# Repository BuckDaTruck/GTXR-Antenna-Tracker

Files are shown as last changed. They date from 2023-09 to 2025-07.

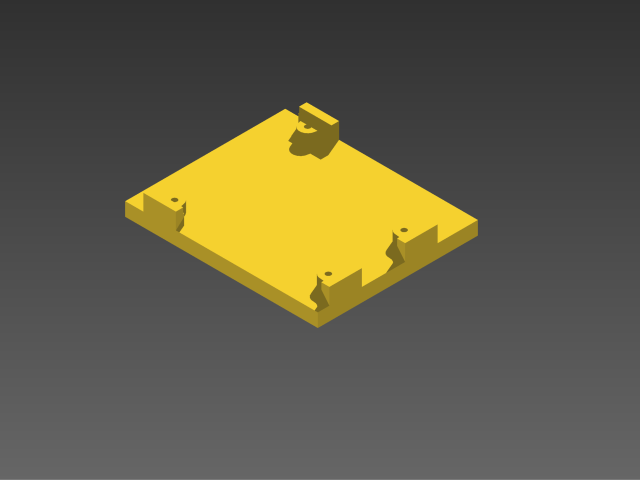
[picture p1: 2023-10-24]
cad/arduino-mounting-bracket-1.snapshot.4/Renderings/Image.png

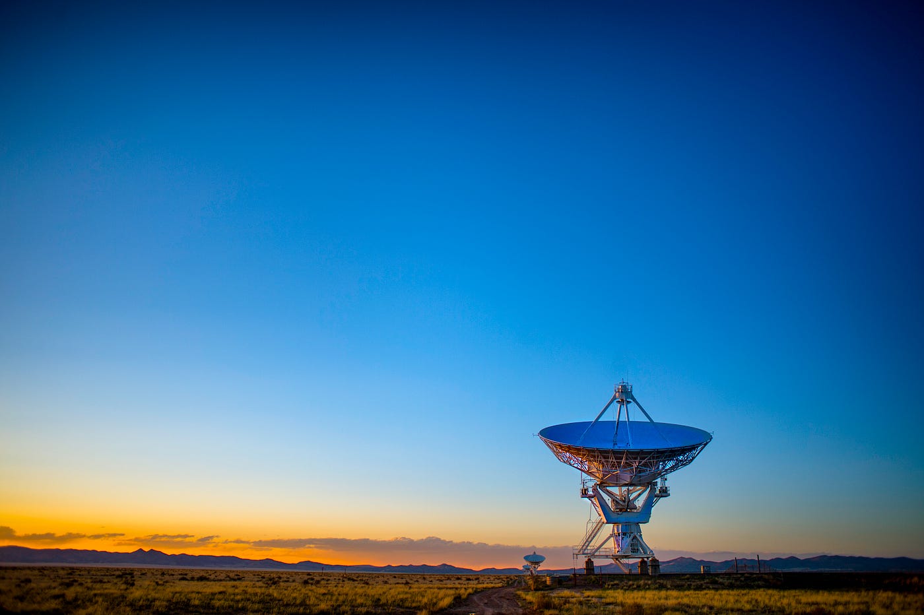
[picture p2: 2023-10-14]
resources/Calculating /0_9QViUdhbDSrmNYS7.jpg

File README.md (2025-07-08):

# GTXR Antenna Tracker

Antenna tracker and ground station software built for the Georgia Tech Experimental Rocketry (GTXR) team. The project combines Python utilities, Arduino firmware, and CAD models for a two-axis tracking platform.

## Overview

The system reads GPS telemetry from a vehicle or Featherweight tracker and calculates the azimuth and elevation required to aim a directional antenna. A stepper-motor driven gimbal points the antenna while a Python application provides a simple user interface and communication with the Arduino controller.

This repository contains everything needed to build the tracker:

- **Python application** (`App/`) for reading GPS data and sending commands to the gimbal
- **Firmware** (`Tracker-Hardware/Firmware/`) for an Arduino-based controller
- **CAD files** (`cad/`) for printing or machining mechanical parts
- **Reference materials and test tools** (`resources/`, `test tools/`)
- **Hardware list** (`PARTS_LIST.md`)

## Repository Layout

```
App/                  Python scripts and GUI assets
Tracker-Hardware/     Arduino firmware
cad/                  STL, STEP, and DXF models for the tracker frame
Assets/               Logos and icons used by the app
FilteredData/         Example telemetry log
resources/            Reference projects and documentation
```

## Software Setup

1. Install Python 3.x
2. Install dependencies:
   ```bash
   pip install numpy pynmea2 pyserial wxPython
   ```
   (Depending on your system you may need additional packages.)
3. Connect the GPS receiver and Arduino-based tracker to your computer.

## Running the Tracker

The main Python application is `App/v2.py`. Launch it with:

```bash
python3 App/v2.py
```

The program listens to GPS data on a serial port and outputs azimuth and elevation commands to the microcontroller. Configure the serial port names in the script if they differ from your setup.

## Hardware and Firmware

The hardware design uses an Arduino with a CNC shield to drive two stepper motors. CAD models for the frame and gears live under `cad/`. Electronic components are listed in `PARTS_LIST.md`.

To load the firmware:

1. Open `Tracker-Hardware/Firmware/Firmware.ino` in the Arduino IDE.
2. Select your board and port.
3. Compile and upload.

## Data and Resources

Example telemetry logs are provided in `FilteredData` and `data.csv`. Additional research code and documentation can be found in the `resources` directory.

## Contact

Developed by Buckley Wiley for GTXR in the fall of 2023. For questions email [buckley@buckleywiley.com](mailto:buckley@buckleywiley.com).

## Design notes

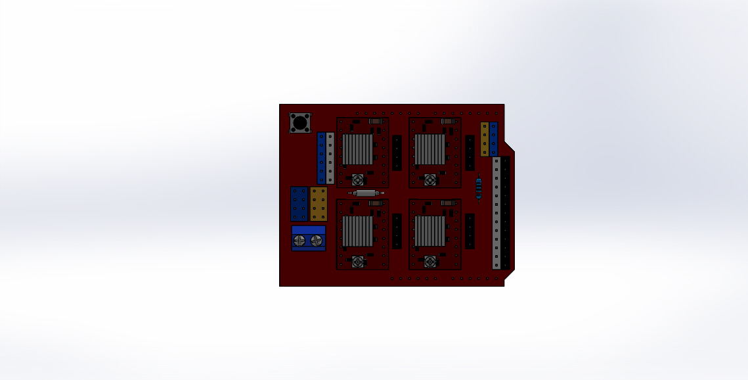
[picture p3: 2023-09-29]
cad/arduino-uno-cnc-shield-v3-a4988-suruculu-1.snapshot.1/Arduino Uno CNC Shield V3 Resim1.JPG

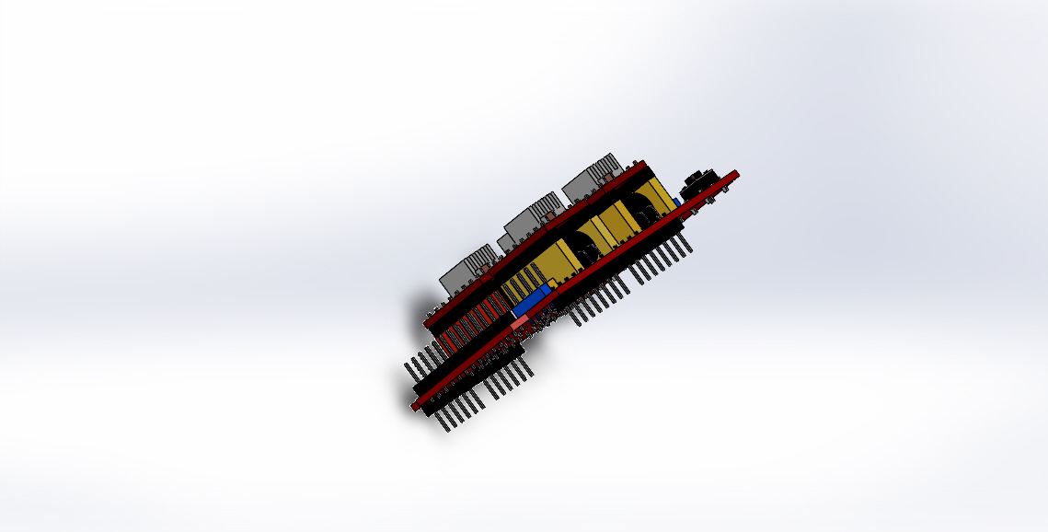
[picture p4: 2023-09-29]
cad/arduino-uno-cnc-shield-v3-a4988-suruculu-1.snapshot.1/Arduino Uno CNC Shield V3 Resim2.JPG

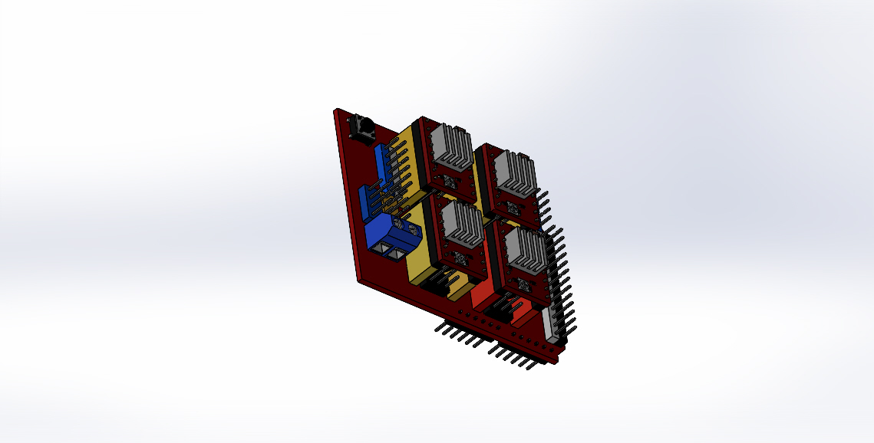
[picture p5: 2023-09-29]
cad/arduino-uno-cnc-shield-v3-a4988-suruculu-1.snapshot.1/Arduino Uno CNC Shield V3 Resim3.JPG

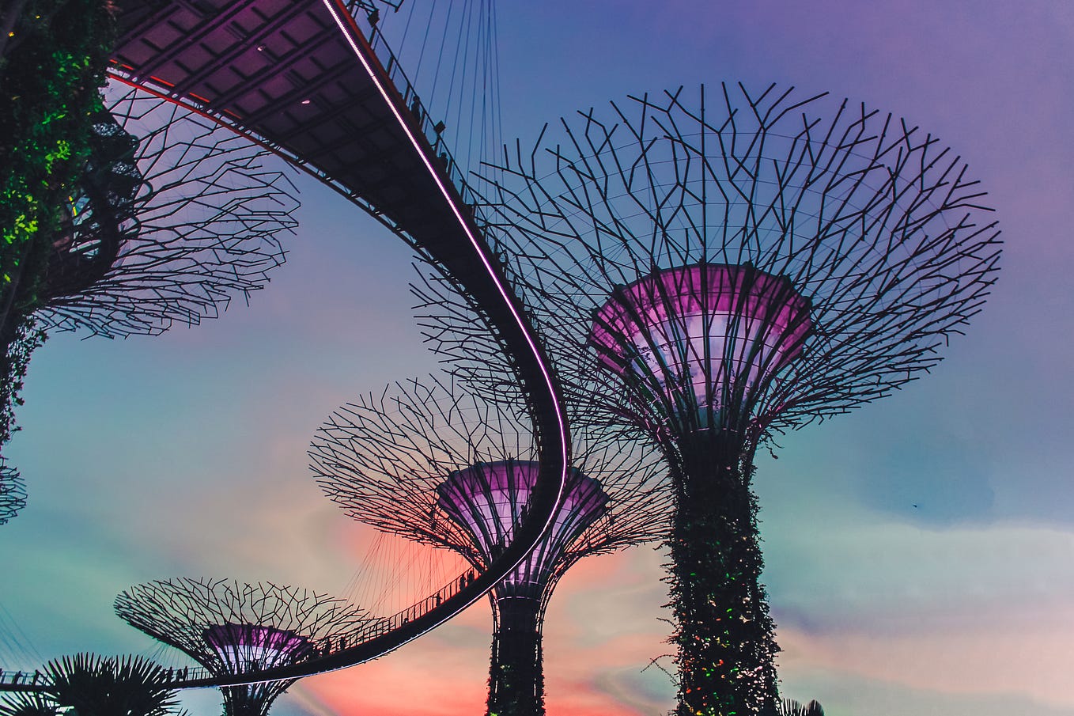
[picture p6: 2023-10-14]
resources/Calculating /0_bAgEUAvxvYWlByFD.jpg

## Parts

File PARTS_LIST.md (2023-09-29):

Parts:
Deep Groove Ball Bearing 80x100x10mm:
    https://a.co/d/d4j6g4g
Deep Groove Ball Bearings 50mm Inner Dia 65mm OD 7mm Bore:
    https://a.co/d/4pUVKYt
24V Power Supply
    https://a.co/d/egXIh8z  
Professional CNC Kit for arduino, GRBL CNC Shield +Kuman Board + RAMPS 1.4 Mechanical Switch Endstop + DRV8825 A4988 GRBL Stepper Motor Driver with Heat Sink + Nema 17 Stepper Motor
    https://a.co/d/038nOvT
GPS Reciever:
    https://a.co/d/1DIF7u9
Featherweight GPS Tracker:
    https://www.featherweightaltimeters.com/store/p22/Featherweight_GPS_Tracker_%28upd%29.html
Baltic Birch Plywood, 6 mm:
    https://a.co/d/dV6v9bX
Hardware:
    1/4" Threaded Inserts:
        https://a.co/d/egDEeNk
    8-32 x 1/2" Button Head Socket Cap Bolts:
        https://a.co/d/85Pqs9Q
    1/4-20 x 1" Button Head Socket Cap Bolts:
        https://a.co/d/cY6eXtJ

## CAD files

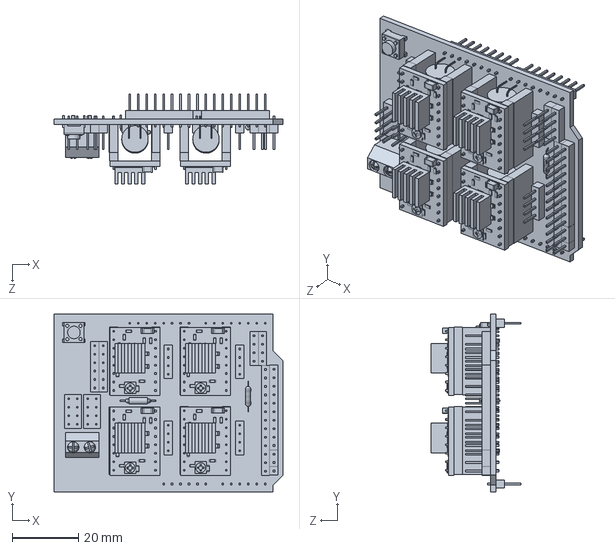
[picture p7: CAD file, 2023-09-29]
cad/arduino-uno-cnc-shield-v3-a4988-suruculu-1.snapshot.1/Arduino Uno CNC Shield V3.SLDPRT
69.0 x 53.5 x 27.1 mm

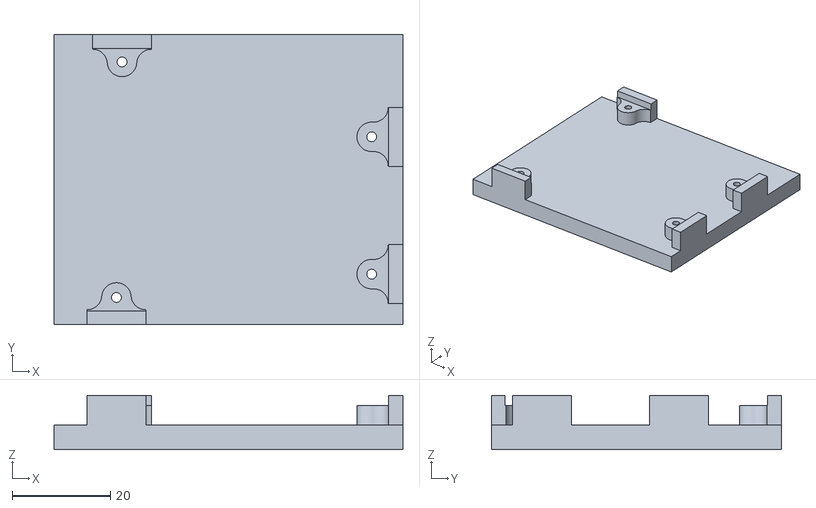
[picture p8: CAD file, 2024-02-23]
cad/Final Cad/Arduino Mount.stl
71.0 x 59.0 x 11.0

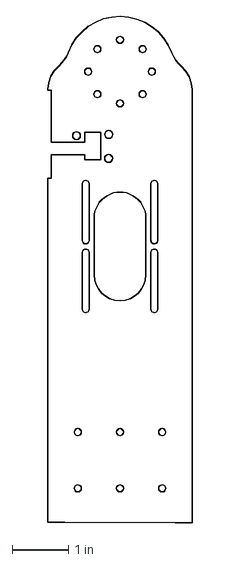
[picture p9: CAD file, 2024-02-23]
cad/hey.dxf
2.56 x 8.99 in

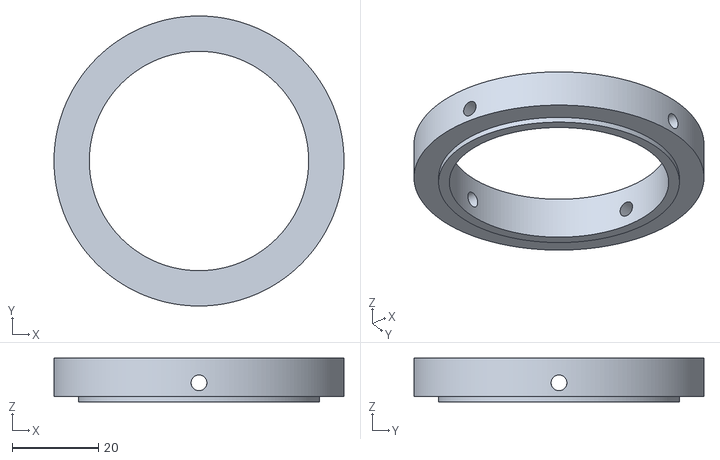
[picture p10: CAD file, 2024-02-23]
cad/Bearing holder.stl
67.2 x 67.2 x 10.2

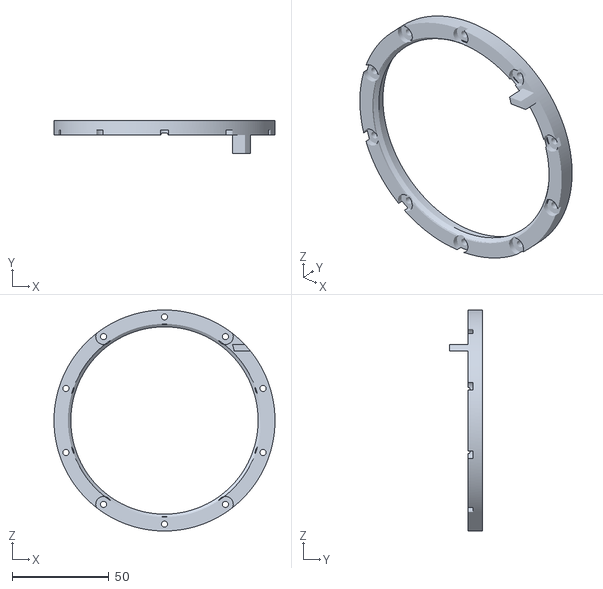
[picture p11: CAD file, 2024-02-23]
cad/Final Cad/pan bearing retainer.stl
114.3 x 17.3 x 114.3

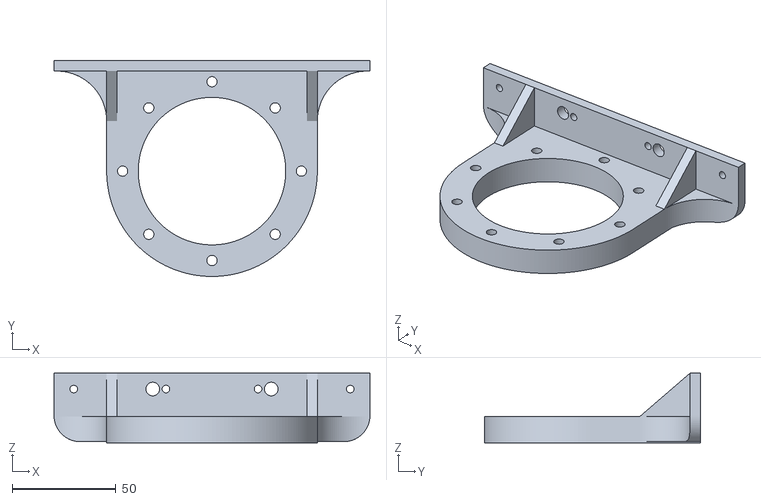
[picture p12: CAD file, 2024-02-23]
cad/Final Cad/antena tray connector.stl
152.4 x 104.1 x 33.5

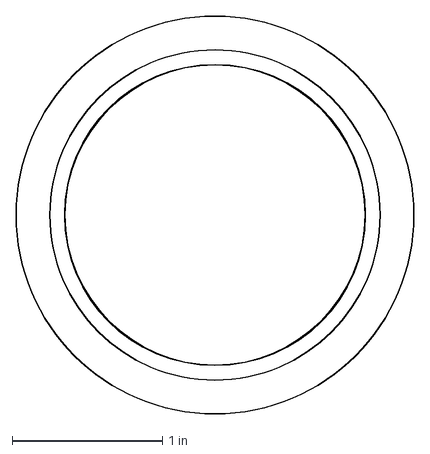
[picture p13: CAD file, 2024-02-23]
cad/Pillar.dxf
2.65 x 2.64 in

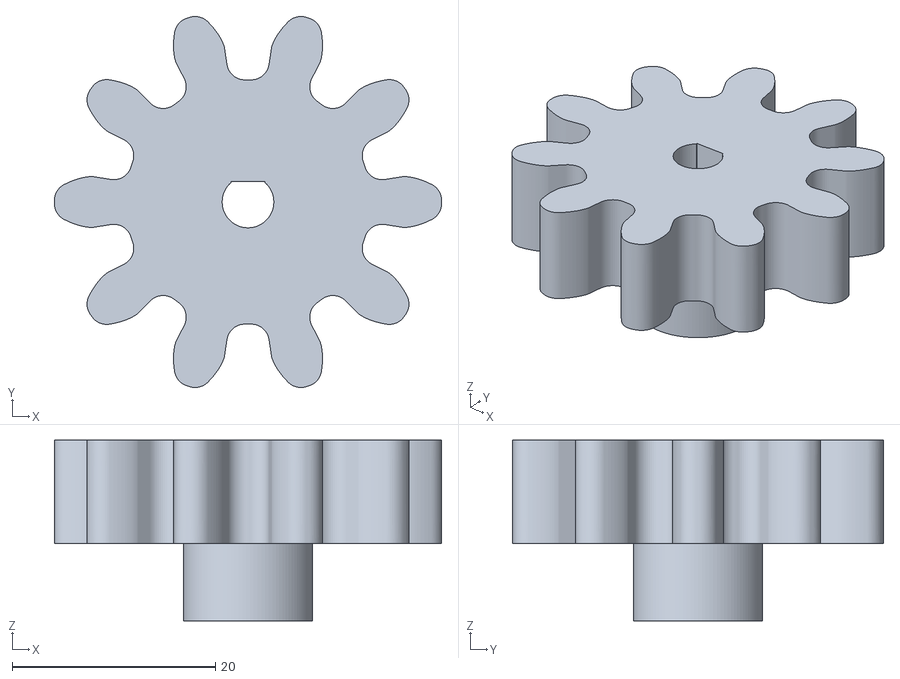
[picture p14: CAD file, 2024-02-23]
cad/Final Cad/stepper gear pan.stl
38.1 x 36.5 x 17.8

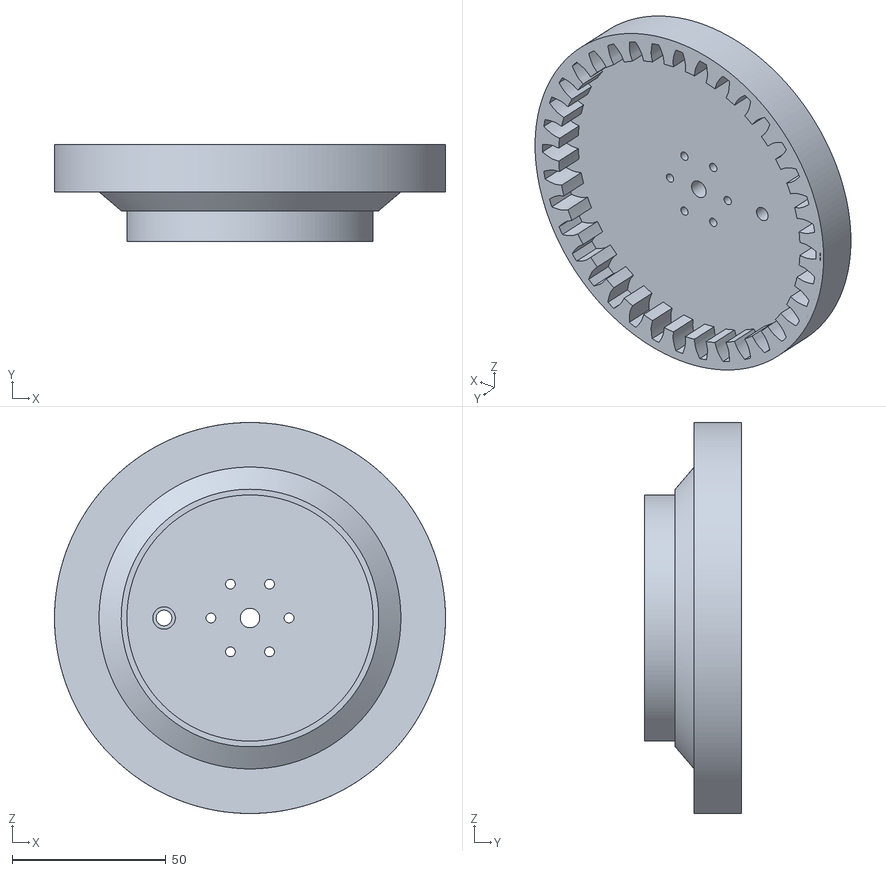
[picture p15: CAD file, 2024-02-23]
cad/Final Cad/Internal gear pan.stl
127.1 x 31.6 x 127.1

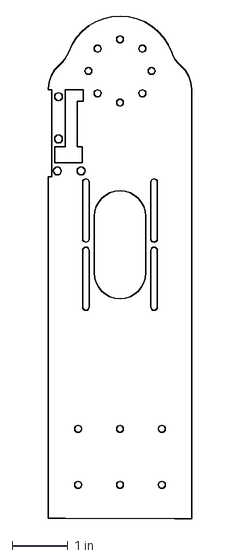
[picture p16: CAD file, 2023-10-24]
cad/Altitude pillar.dxf
2.56 x 8.99 in

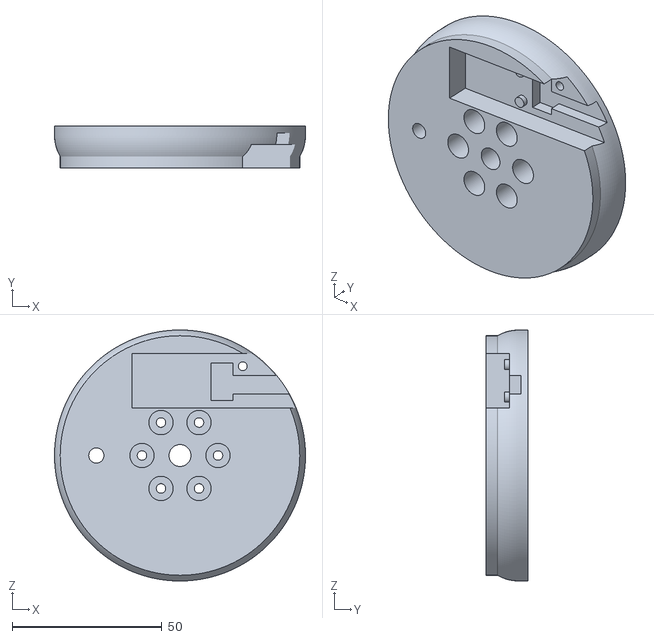
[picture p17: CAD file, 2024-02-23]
cad/Final Cad/Bottom mount.stl
83.8 x 14.0 x 83.8

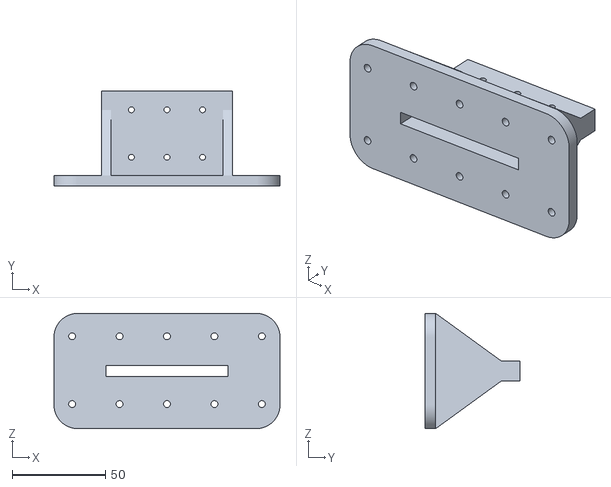
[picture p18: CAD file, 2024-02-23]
cad/Final Cad/Pylon Stand.stl
121.0 x 50.8 x 61.7

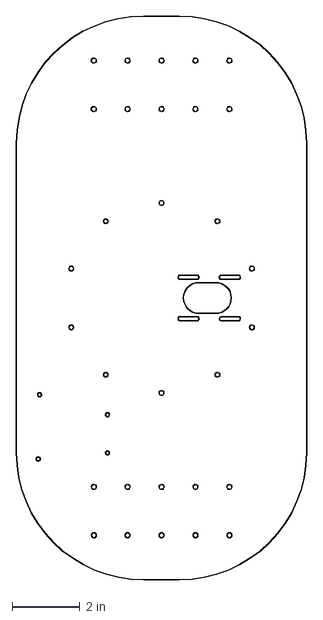
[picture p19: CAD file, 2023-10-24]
cad/Pan Plate.dxf
8.56 x 16.6 in

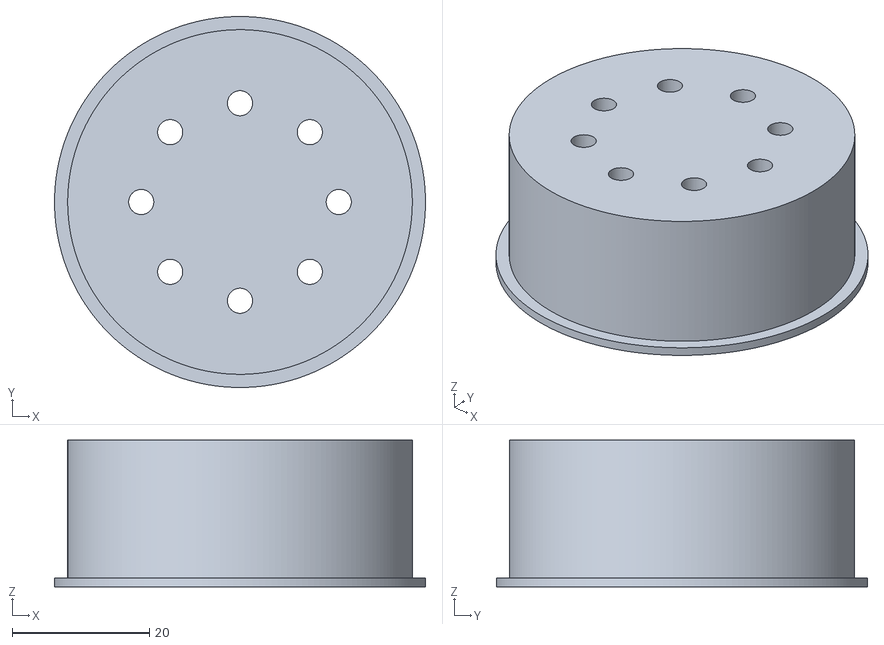
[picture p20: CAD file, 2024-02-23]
cad/Final Cad/azimuth bearing connector.stl
54.0 x 54.0 x 21.3

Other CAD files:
cad/pan spur gear.stl
cad/ardunio_mount.stl
cad/Pan tray mount.stl
cad/bottom clamp.stl
cad/Bewaring holder.stl
cad/Body1.stl
cad/Final Cad/Bearing Retainer.stl
cad/Final Cad/Pan Plate mount.stl
cad/Final Cad/Tilt gear with home.stl
cad/Final Cad/Tilt gear.stl
cad/Switch.SLDPRT
cad/antenna carrier plate.dxf
cad/arduino-mounting-bracket-1.snapshot.4/Renderings/Uno R3-mount.ipt
cad/arduino-mounting-bracket-1.snapshot.4/Uno R3-mount.ipt
cad/arduino-uno-cnc-shield-v3-a4988-suruculu-1.snapshot.1/Arduino Uno CNC Shield V3.stl
cad/azimuth bearing connector.stl
cad/azimuth gear with endstop.stl
cad/azimuth pillar.dxf
cad/internal gear pan.stl
cad/plateconnector.stl
cad/stepper gear azimuth.stl
cad/tripod mount.stl
cad/vertical connector.stl

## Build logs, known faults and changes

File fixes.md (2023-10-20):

Traceback (most recent call last):
  File "/Users/buckleywiley/Projects/GTXR internship/GTXR-Antenna-Tracker/calculator.py", line 557, in OnInputChange
    self.update_calculations()
  File "/Users/buckleywiley/Projects/GTXR internship/GTXR-Antenna-Tracker/calculator.py", line 545, in update_calculations
    self.ser.write(Altitude_bytes)
  File "/Library/Frameworks/Python.framework/Versions/3.11/lib/python3.11/site-packages/serial/serialposix.py", line 615, in write
    raise PortNotOpenError()
serial.serialutil.PortNotOpenError: Attempting to use a port that is not open
{'lat': 0.0, 'lon': 0.0, 'elv': 0.0}
{'lat': 32.0, 'lon': 32.0, 'elv': 4343.0}
Results:
Distance: 2961.871 miles
Azimuth: 40.4895°
Altitude: -22.0024°
Traceback (most recent call last):
  File "/Users/buckleywiley/Projects/GTXR internship/GTXR-Antenna-Tracker/calculator.py", line 557, in OnInputChange
    self.update_calculations()
  File "/Users/buckleywiley/Projects/GTXR internship/GTXR-Antenna-Tracker/calculator.py", line 545, in update_calculations
    self.ser.write(Altitude_bytes)
  File "/Library/Frameworks/Python.framework/Versions/3.11/lib/python3.11/site-packages/serial/serialposix.py", line 615, in write
    raise PortNotOpenError()
serial.serialutil.PortNotOpenError: Attempting to use a port that is not open
Opened Serial Port (Featherweight GPS): /dev/cu.Bluetooth-Incoming-Port
Selected Serial Port (Featherweight GPS): /dev/cu.Bluetooth-Incoming-Port
1: Serial Port: /dev/cu.Bluetooth-Incoming-Port, Description: n/a
Traceback (most recent call last):
  File "/Users/buckleywiley/Projects/GTXR internship/GTXR-Antenna-Tracker/calculator.py", line 450, in rescan_serial_ports
    self.serial_port_choice.Clear()
    ^^^^^^^^^^^^^^^^^^^^^^^
AttributeError: 'Example' object has no attribute 'serial_port_choice'
1: Serial Port: /dev/cu.Bluetooth-Incoming-Port, Description: n/a
Traceback (most recent call last):
  File "/Users/buckleywiley/Projects/GTXR internship/GTXR-Antenna-Tracker/calculator.py", line 450, in rescan_serial_ports
    self.serial_port_choice.Clear()
    ^^^^^^^^^^^^^^^^^^^^^^^
AttributeError: 'Example' object has no attribute 'serial_port_choice'
1: Serial Port: /dev/cu.Bluetooth-Incoming-Port, Description: n/a
Traceback (most recent call last):
  File "/Users/buckleywiley/Projects/GTXR internship/GTXR-Antenna-Tracker/calculator.py", line 450, in rescan_serial_ports
    self.serial_port_choice.Clear()
    ^^^^^^^^^^^^^^^^^^^^^^^
AttributeError: 'Example' object has no attribute 'serial_port_choice'
1: Serial Port: /dev/cu.Bluetooth-Incoming-Port, Description: n/a
Traceback (most recent call last):
  File "/Users/buckleywiley/Projects/GTXR internship/GTXR-Antenna-Tracker/calculator.py", line 450, in rescan_serial_ports
    self.serial_port_choice.Clear()
    ^^^^^^^^^^^^^^^^^^^^^^^
AttributeError: 'Example' object has no attribute 'serial_port_choice'

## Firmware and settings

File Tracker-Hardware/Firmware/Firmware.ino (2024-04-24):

#include <CNCShield.h>

#define NO_OF_STEPS 6000
#define SLEEP_BETWEEN_STEPS_MS 3
#define SPEED_STEPS_PER_SECOND 475
const int buttonTilt = 9;  // Pin for tilt limit switch
const int buttonPan = 10;  // Pin for pan limit switch
bool stopTilt = false;
bool stopPan = false;
int tiltState = 1;
int PanState = 1;
CNCShield cnc_shield;
StepperMotor *motorTilt = cnc_shield.get_motor(0);
StepperMotor *motorPan = cnc_shield.get_motor(1);

int currentPanPosition = 0;
int currentTiltPosition = 0;

void setup() {
  Serial.begin(115200);
  Serial.println("I am Alive");
  pinMode(buttonPan, INPUT_PULLUP);
  pinMode(buttonTilt, INPUT_PULLUP);

  cnc_shield.begin();
  cnc_shield.enable();
  home();
}

void home() {
   motorPan->set_dir(COUNTER);
  motorTilt->set_dir(COUNTER);
  motorPan->set_speed(SPEED_STEPS_PER_SECOND);
  motorTilt->set_speed(SPEED_STEPS_PER_SECOND);
  motorPan->step(125);
  motorTilt->step(125);

  motorPan->set_dir(CLOCKWISE);
  motorTilt->set_dir(CLOCKWISE);

  while (stopPan == false) {
    int panState = digitalRead(buttonPan);
    motorPan->step();
    delay(SLEEP_BETWEEN_STEPS_MS);
    if (panState == LOW) {
      stopPan = true;
    }
  }

  while (stopTilt == false) {
    int tiltState = digitalRead(buttonTilt);
    motorTilt->step();
    delay(SLEEP_BETWEEN_STEPS_MS);
    if (tiltState == LOW) {
      stopTilt = true;
    }
  }
  stopTilt = false;
  stopPan = false;
  tiltState = 1;
  PanState = 1;
  // Reset positions
  currentPanPosition = 0;
  currentTiltPosition = 0;
  moveMotorsToAngle(10, 15);
}
void loop() {
  if (Serial.available()) {  //example command for this sentax "M3 175" 3 degree pan 175 tilt
    String command = Serial.readStringUntil('\n');
    if (command.startsWith("M")) {
      Serial.println("Moving!");
      int separatorIndex = command.indexOf(' ');
      int panAngle = command.substring(1, separatorIndex).toInt();
      int tiltAngle = command.substring(separatorIndex + 1).toInt();
      //Serial.println("Angles Pan" + panAngle.toString() + "Tilt" + tiltAngle.toString());
      moveMotorsToAngle(panAngle, tiltAngle);
    } else if (command.startsWith("H")) {
      Serial.println("homing!");
      home();
    }
  }
  /*if (Serial.available() > 0) {// this is for the python script
  
    char command = Serial.read();
    if (command == 'H') {
      home();
    } else if (command == 'M') {

      if (Serial.available() >= 8) {
        int panAngle, tiltAngle;
        Serial.readBytes((char *)&panAngle, sizeof(panAngle));
        Serial.readBytes((char *)&tiltAngle, sizeof(tiltAngle));
        moveMotorsToAngle(panAngle, tiltAngle);
      }
      
  }*/
}
void moveMotorsToAngle(int panAngle, int tiltAngle) {
  // Calculate steps from angles
  if (panAngle > 340) {
    panAngle = 340;
  }
  if (tiltAngle > 90) {
    tiltAngle = 90;
  }
  
  int targetPanSteps = map(panAngle, 0, 360, 0, NO_OF_STEPS);
  int targetTiltSteps = map(tiltAngle, 0, 360, 0, NO_OF_STEPS);
  if (currentPanPosition < targetPanSteps) {
    motorPan->set_dir(COUNTER);
  } else if (currentPanPosition > targetPanSteps) {
    motorPan->set_dir(CLOCKWISE);
  }
  if (currentTiltPosition < targetTiltSteps) {
    motorTilt->set_dir(COUNTER);
  } else if (currentTiltPosition > targetTiltSteps) {
    motorTilt->set_dir(CLOCKWISE);
  }

  // Calculate difference from current position
  int panStepDiff = abs(targetPanSteps - currentPanPosition);
  int tiltStepDiff = abs(targetTiltSteps - currentTiltPosition);

  // Move motors
  motorPan->set_speed(SPEED_STEPS_PER_SECOND);
  motorTilt->set_speed(SPEED_STEPS_PER_SECOND);
  motorPan->step(panStepDiff);
  motorTilt->step(tiltStepDiff);

  // Update current positions
  currentPanPosition = targetPanSteps;
  currentTiltPosition = targetTiltSteps;
}

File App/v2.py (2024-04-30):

import serial
import pynmea2
import numpy as np
import math
import time
EQUATORIAL_RADIUS_FEET = 20925721.785
POLAR_RADIUS_FEET = 20855567.585


def parse_angle(angle_str, limit):
    """
    Parses an angle string and returns the angle as a float if it is within the specified limit.

    Args:
        angle_str (str): The angle string to parse.
        limit (float): The limit within which the angle must be.

    Returns:
        float or None: The parsed angle as a float if it is within the limit, or None if it is not.
    """
    try:
        angle = float(angle_str)
        if math.isnan(angle) or (angle < -limit) or (angle > limit):
            print("Invalid angle value.")
            return None
        else:
            return angle
    except ValueError:
        print("Invalid angle value. Please enter a numeric value.")
        return None
    
def parse_elevation(elevation_str):
    """
    Parses the given elevation string and returns the elevation in feet.

    Args:
        elevation_str (str): The string representation of the elevation.

    Returns:
        float: The elevation in feet if the string is a valid numeric value, otherwise None.
    """
    try:
        elevation_feet = float(elevation_str)
        if math.isnan(elevation_feet):
            print("Invalid elevation value.")
            return None
        else:
            return elevation_feet
    except ValueError:
        print("Invalid elevation value. Please enter a numeric value.")
        return None

def parse_location(lati, long, alt):
    """
    Parses the latitude, longitude, and altitude strings and returns a dictionary containing the parsed values.

    Args:
        lati (str): The latitude string.
        long (str): The longitude string.
        alt (str): The altitude string.

    Returns:
        dict: A dictionary containing the parsed latitude, longitude, and altitude values. Returns None if any of the strings cannot be parsed.
    """
    lat_str = lati
    lon_str = long
    elv_str = alt

    lat = parse_angle(lat_str, 90.0)
    if lat is not None:
        lon = parse_angle(lon_str, 180.0)
        if lon is not None:
            elv = parse_elevation(elv_str)
            if elv is not None:
                location = {'lat': lat, 'lon': lon, 'elv': elv}
                #print(location)
                return location
    return None

def earth_radius_in_feet(latitude_radians):
    """
    Calculates the radius of the earth in feet at a given latitude.

    Args:
        latitude_radians (float): The latitude in radians.

    Returns:
        float: The radius of the earth in feet at the given latitude.
    """
    a = 20925721.785  # equatorial radius in feet
    b = 20855567.585  # polar radius in feet
    cos = math.cos(latitude_radians)
    sin = math.sin(latitude_radians)
    t1 = a * a * cos
    t2 = b * b * sin
    t3 = a * cos
    t4 = b * sin
    return math.sqrt((t1 * t1 + t2 * t2) / (t3 * t3 + t4 * t4))

def geocentric_latitude(lat):
    """
    Calculates the geocentric latitude from the given geodetic latitude.

    Args:
        lat (float): The geodetic latitude in radians.

    Returns:
        float: The geocentric latitude in radians.
    """
    e2 = 0.00669437999014
    clat = math.atan((1.0 - e2) * math.tan(lat))
    return clat

def location_to_point(c):
    """
    Converts a location on Earth to a point in 3D space.

    Args:
        c (dict): A dictionary containing the latitude, longitude, and elevation of the location.

    Returns:
        dict: A dictionary containing the x, y, and z coordinates of the point, as well as the radius of the Earth at that location and the normal vector of the point.
    """
    lat = c['lat'] * math.pi / 180.0
    lon = c['lon'] * math.pi / 180.0
    radius = earth_radius_in_feet(lat)
    clat = geocentric_latitude(lat)
    cos_lon = math.cos(lon)
    sin_lon = math.sin(lon)
    cos_lat = math.cos(clat)
    sin_lat = math.sin(clat)
    x = radius * cos_lon * cos_lat
    y = radius * sin_lon * cos_lat
    z = radius * sin_lat
    cos_glat = math.cos(lat)
    sin_glat = math.sin(lat)
    nx = cos_glat * cos_lon
    ny = cos_glat * sin_lon
    nz = sin_glat
    x += c['elv'] * nx
    y += c['elv'] * ny
    z += c['elv'] * nz
    return {'x': x, 'y': y, 'z': z, 'radius': radius, 'nx': nx, 'ny': ny, 'nz': nz}

def distance(ap, bp):
    """
    Calculates the Euclidean distance between two points in 3D space.

    Args:
        ap (dict): A dictionary representing the coordinates of the first point.
        bp (dict): A dictionary representing the coordinates of the second point.

    Returns:
        float: The Euclidean distance between the two points.
    """
    dx = ap['x'] - bp['x']
    dy = ap['y'] - bp['y']
    dz = ap['z'] - bp['z']
    return math.sqrt(dx * dx + dy * dy + dz * dz)

def rotate_globe(b, a, bradius, aradius):
    """
    Rotate a point on the surface of a sphere around another point on the surface of the same sphere.

    Args:
        b (dict): A dictionary representing the point to be rotated, with keys 'lat', 'lon', and 'elv'.
        a (dict): A dictionary representing the point around which to rotate, with keys 'lat', 'lon', and 'elv'.
        bradius (float): The radius of the sphere at the point to be rotated.
        aradius (float): The radius of the sphere at the point around which to rotate.

    Returns:
        dict: A dictionary representing the rotated point, with keys 'x', 'y', 'z', and 'radius'.
    """
    br = {'lat': b['lat'], 'lon': (b['lon'] - a['lon']), 'elv': b['elv']}
    brp = location_to_point(br)
    alat = geocentric_latitude(-a['lat'] * math.pi / 180.0)
    acos = math.cos(alat)
    asin = math.sin(alat)
    bx = (brp['x'] * acos) - (brp['z'] * asin)
    by = brp['y']
    bz = (brp['x'] * asin) + (brp['z'] * acos)
    return {'x': bx, 'y': by, 'z': bz, 'radius': bradius}

def normalize_vector_diff(b, a):
    """
    Calculates the normalized vector difference between two points in 3D space.

    Args:
        b (dict): A dictionary representing the second point in 3D space with keys 'x', 'y', and 'z'.
        a (dict): A dictionary representing the first point in 3D space with keys 'x', 'y', and 'z'.

    Returns:
        dict: A dictionary representing the normalized vector difference between the two points with keys 'x', 'y', 'z', and 'radius'.
              The 'x', 'y', and 'z' keys represent the normalized vector components, and the 'radius' key represents the magnitude of the vector.
              Returns None if the two points are the same.
    """
    dx = b['x'] - a['x']
    dy = b['y'] - a['y']
    dz = b['z'] - a['z']
    dist2 = dx * dx + dy * dy + dz * dz
    if dist2 == 0:
        return None
    dist = math.sqrt(dist2)
    return {'x': (dx / dist), 'y': (dy / dist), 'z': (dz / dist), 'radius': 1.0}
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

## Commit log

2023-09-29 fixed everthing in main calc
    [calc.py, calculator.py, parse data.py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]
2023-09-29 added cad
    [Arduino Uno CNC Shield V3.SLDPRT, Arduino Uno CNC Shield V3.stl, Bewaring holder.stl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]
2023-10-12 Worked on test code
    [data.csv]
